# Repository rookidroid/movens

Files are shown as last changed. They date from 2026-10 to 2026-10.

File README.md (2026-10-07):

<p align="center">
  <picture>
    <source media="(prefers-color-scheme: dark)" srcset="logo/movens-logo-dark.svg">
    Movens
  </picture>
</p>

<p align="center">
  A 3D-printed, 5-axis robotic arm with a gripper, driven by an ESP32 and controlled from your browser.
</p>

---

Movens is a heavily modified fork of the [BCN3D Moveo](https://github.com/BCN3D/BCN3D-Moveo), the open-source educational arm. The mechanical design keeps Moveo's printed structure but replaces several parts. The electronics and firmware are new. Instead of Marlin on an Arduino Mega + RAMPS with G-code over USB, Movens runs its own firmware on an ESP32 and serves a web control panel over WiFi. There's nothing to install on the computer or phone you control it from.

*Movens* is Latin for "moving", from the same verb as *Moveo* ("I move").

## Features

- **Browser control panel** served by the arm itself, with light and dark themes and no internet access needed
- **Joint control:** jog or type a target angle for each of the five joints, plus the gripper servo
- **Cartesian control:** jog the tool in X / Y / Z and pitch, or go straight to a pose. Inverse kinematics picks the closest valid solution within the joint limits.
- **Synchronized moves:** all joints start and finish together, so the tool moves smoothly
- **Guided calibration** per joint: steps per degree, home angle, speed, acceleration, and soft limits. It's saved on the board and survives reboots.
- **WiFi setup from the browser:** join your network (reachable at `http://movens.local`), or fall back to the arm's own access point
- **Emergency stop** in every page, also bound to the <kbd>Esc</kbd> key
- **Over-the-air firmware updates** from the Arduino IDE once the arm is on your network
- **REST API**, so you can drive the arm from scripts as well as the web UI

## Hardware

| | |
|---|---|
| Controller | ESP32 development board (classic ESP32, e.g. *ESP32 Dev Module*) |
| Joints J1–J5 | Stepper motors, each on a STEP/DIR driver |
| Gripper | Hobby servo, driven at 700–2300 µs |
| Structure | 3D-printed parts. See [Repository layout](#repository-layout). |

### Wiring

Default pins, set in [`movens_config.h`](firmware/movens/movens_config.h):

| Joint | Role | STEP | DIR |
|---|---|---|---|
| J1 | Base yaw | 12 | 13 |
| J2 | Shoulder | 27 | 14 |
| J3 | Elbow | 25 | 26 |
| J4 | Wrist roll | 32 | 33 |
| J5 | Wrist pitch | 2 | 15 |
| Gripper | Servo signal | 4 | |

Stepper drivers need their own motor supply. Tie the drivers' logic ground to the ESP32 ground.

## Firmware

The firmware lives in [`firmware/movens`](firmware/movens) and builds with the Arduino IDE or `arduino-cli`.

### Requirements

- [Arduino-ESP32 core](https://github.com/espressif/arduino-esp32) (Boards Manager: *esp32 by Espressif Systems*)
- Libraries, from the Library Manager:
  - [FastAccelStepper](https://github.com/gin66/FastAccelStepper)
  - [ESP32Servo](https://github.com/madhephaestus/ESP32Servo)
  - [ESPAsyncWebServer](https://github.com/ESP32Async/ESPAsyncWebServer) and [AsyncTCP](https://github.com/ESP32Async/AsyncTCP)

`WiFi`, `Preferences` and `ArduinoOTA` come with the ESP32 core.

### Configure and flash

1. Open `firmware/movens/movens.ino`.
2. Review [`movens_config.h`](firmware/movens/movens_config.h): pins, stepper speed and acceleration, gripper servo range, and the access-point name and password. **Change the default AP password (`movens_1234`).**
3. Measure your arm and update the `KIN_*` link lengths in the same file. They're used by the Cartesian control.
4. Select your ESP32 board and port, then upload.

Once the arm is on your WiFi network, later updates can go over the air. Pick the `movens` network port in the Arduino IDE.

### Module layout

| File | Purpose |
|---|---|
| `movens.ino` | Setup and the main loop (Core 1) |
| `movens_config.h` | Pins, servo range, WiFi defaults, arm geometry |
| `joints.*` | Stepper engine, J1–J5 steppers, gripper servo |
| `calibration.*` | Steps ↔ degrees, soft limits, saving to flash (NVS) |
| `kinematics.*` | Forward and inverse kinematics (tool pose ↔ joint angles) |
| `commands.*` | FreeRTOS queue from web handlers (Core 0) to the motion loop (Core 1) |
| `connectivity.*` | WiFi station / access-point fallback, saved network, OTA |
| `web_server.*` | HTTP routes and REST API |
| `web_*.h` | Embedded HTML, CSS, JS and favicon for the web UI |
| `json_util.*` | Minimal JSON number parsing |

## Getting started

1. **Power on in the alignment pose.** Each joint's step counter starts at 0 at power-on, so put every joint on its alignment marks before switching on.
2. **Connect.** On first boot the arm starts an access point named `movens`. Join it and open `http://192.168.4.1`.
3. **Join your network (optional).** On the **Network** page, pick your WiFi and save. The arm restarts and joins it. Open `http://movens.local` or the IP your router assigned. If it can't connect, it falls back to the `movens` access point.
4. **Calibrate each joint** on the **Calibrate** page:
   1. Zero the counter at the alignment pose.
   2. Jog to two poses whose angles you can measure, as far apart as the joint allows, and record each one. Approach both from the same direction so backlash doesn't skew the result.
   3. Check the computed steps per degree, set speed, acceleration and soft limits, then save.
   4. Verify by commanding a few angles.
5. **Move the arm** from the **Control** page, by joint or in Cartesian space. Cartesian control needs all five joints calibrated.

Joint angle conventions, like where zero is and which way is positive, must match those described in [`movens_config.h`](firmware/movens/movens_config.h) for the kinematics to be correct.

## REST API

Every page in the web UI uses this API, and you can call it directly. POST bodies are JSON.

| Method | Path | Body / reply |
|---|---|---|
| GET | `/status` | Steps (`jN`), angles (`aN`), moving flags (`mN`) and tool pose (`x y z pitch yaw`) |
| POST | `/move` | `{joint, steps}`: relative move |
| POST | `/moveto` | `{joint, pos}`: absolute move in steps |
| POST | `/moveangle` | `{joint, deg}`: absolute move in degrees |
| POST | `/movejoints` | `{a1..a5 \| j1..j5, speed?}`: synchronized multi-joint move |
| POST | `/movepose` | `{x, y, z, pitch, yaw?, rel?, dry?, speed?}`: IK move to a tool pose |
| POST | `/setpos` | `{joint, deg}` or `{joint, steps}`: redefine current position, no motion |
| POST | `/servo` | `{us}`: gripper servo pulse width |
| POST | `/stop` | Stop all motors immediately |
| POST | `/home` | Move all joints to step 0 |
| GET / POST | `/config` | Speed and acceleration per joint |
| GET / POST | `/calib` | Calibration and saved motion profile per joint |
| GET / POST | `/wifi` | Current connection and saved network. POST `{ssid, password?}` |
| GET | `/wifiscan` | Nearby networks |

Example: move the tool 20 mm up from where it is now.

```bash
curl -X POST http://movens.local/movepose -d '{"z":20,"pitch":0,"rel":1}'
```

## Repository layout

| Path | Contents |
|---|---|
| [`firmware/movens`](firmware/movens) | Movens ESP32 firmware and web UI |
| [`cad`](cad) | Movens parts: new and modified designs (STEP / STL / 3MF) and the Fusion 360 assembly |
| [`logo`](logo) | Movens logo, icon and favicon (SVG, light and dark) |
| [`archive/moveo`](archive/moveo) | Original BCN3D Moveo files: SolidWorks CAD, Marlin firmware, BOM and user manual (not used by Movens) |
| [`archive/legacy`](archive/legacy) | Earlier Movens iterations, kept for reference |

The original [Moveo manual](archive/moveo/manual) is still the best guide to printing and assembling the shared structural parts.

## Credits

- [**BCN3D Moveo**](https://github.com/BCN3D/BCN3D-Moveo) by BCN3D Technologies, developed with the Departament d'Ensenyament of the Generalitat de Catalunya. Movens is a fork of this project.
- The Moveo is itself based on the [BetaBots Robot Arm](https://hackaday.io/project/3800-3d-printable-robot-arm) by [Andreas Hölldorfer](http://chaozlabs.blogspot.de/) ([GitHub](https://github.com/4ndreas/BetaBots-Robot-Arm-Project)).

## License

[MIT](LICENSE). The original BCN3D Moveo copyright notice is kept, as the license requires.

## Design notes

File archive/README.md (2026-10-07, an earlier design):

# Archive

Files kept for reference. Nothing here is used by the current Movens build.

## [`moveo`](moveo)

Original files from the [BCN3D Moveo](https://github.com/BCN3D/BCN3D-Moveo), which Movens is forked from.

| Path | Contents |
|---|---|
| [`cad`](moveo/cad) | SolidWorks parts and assemblies |
| [`firmware/Marlin_BCN3D_Moveo`](moveo/firmware/Marlin_BCN3D_Moveo) | Marlin firmware for Arduino Mega + RAMPS |
| [`bom`](moveo/bom) | Bill of materials |
| [`manual`](moveo/manual) | User and assembly manual |

The manual is still the best guide to printing and assembling the structural parts Movens shares with the Moveo.

## [`legacy`](legacy)

Earlier Movens iterations, superseded by the files in [`cad`](../cad). Not maintained.

| Path | Contents |
|---|---|
| [`movens.f3d`](legacy) | Older Fusion 360 assembly (current one is [`cad/movens.f3d`](../cad/movens.f3d)) |
| [`parts.f3d`](legacy), [`1M3A.STEP`](legacy) | Loose parts from earlier work |
| [`uno box`](legacy/uno%20box) | Controller enclosure from an earlier Arduino Uno build |
| [`temp`](legacy/temp) | Scratch STLs |

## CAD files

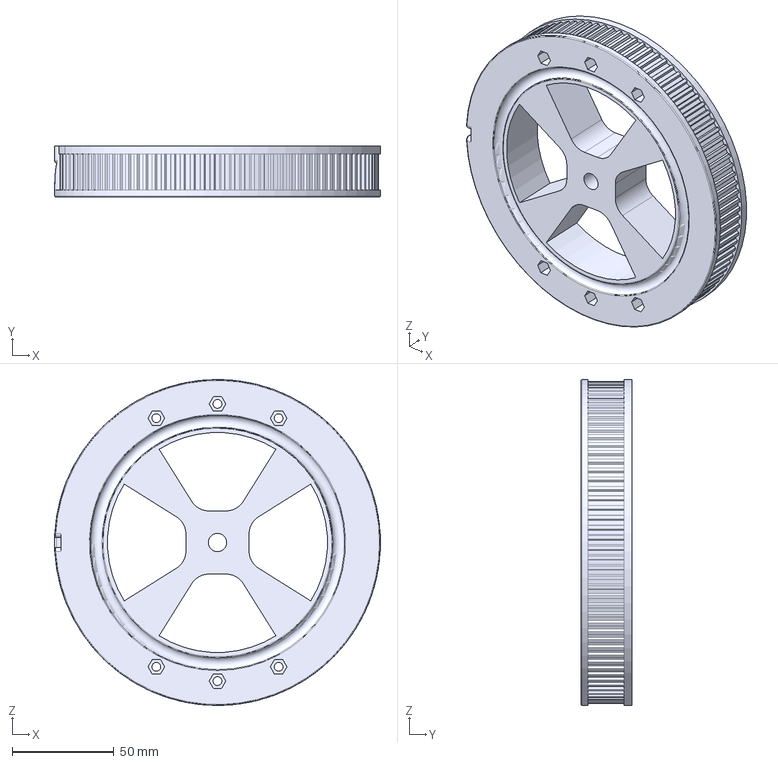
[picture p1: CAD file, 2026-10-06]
cad/movens base wheel.step
160.0 x 25.0 x 160.0 mm

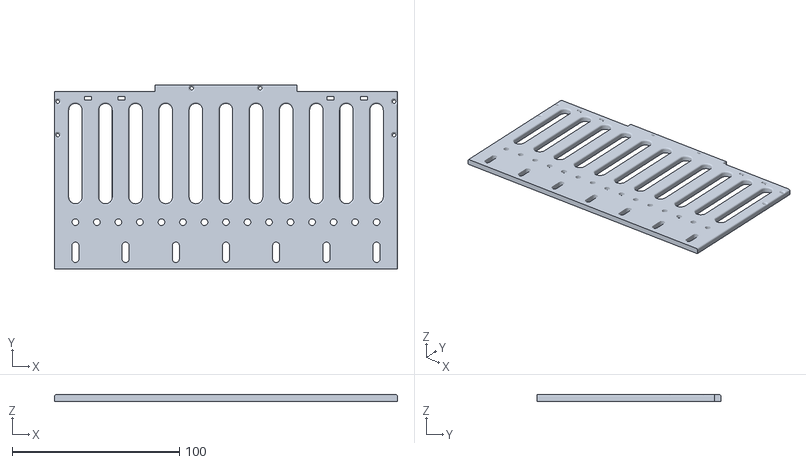
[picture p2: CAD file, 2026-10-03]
temp/side_long.stl
205.0 x 110.0 x 4.00

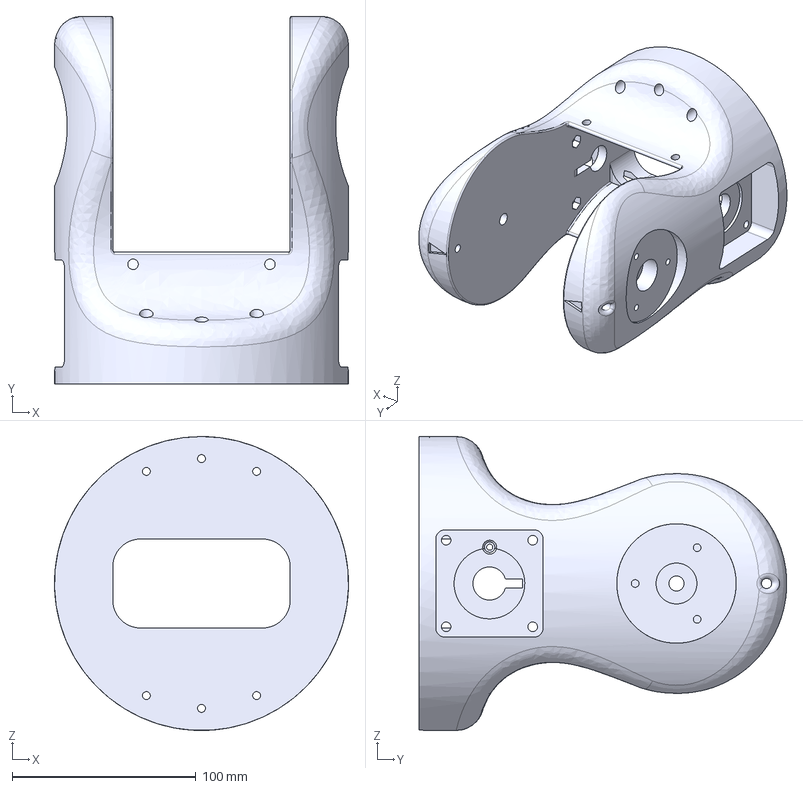
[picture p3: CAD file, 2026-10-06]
cad/movens j2.step
160.0 x 200.0 x 160.0 mm

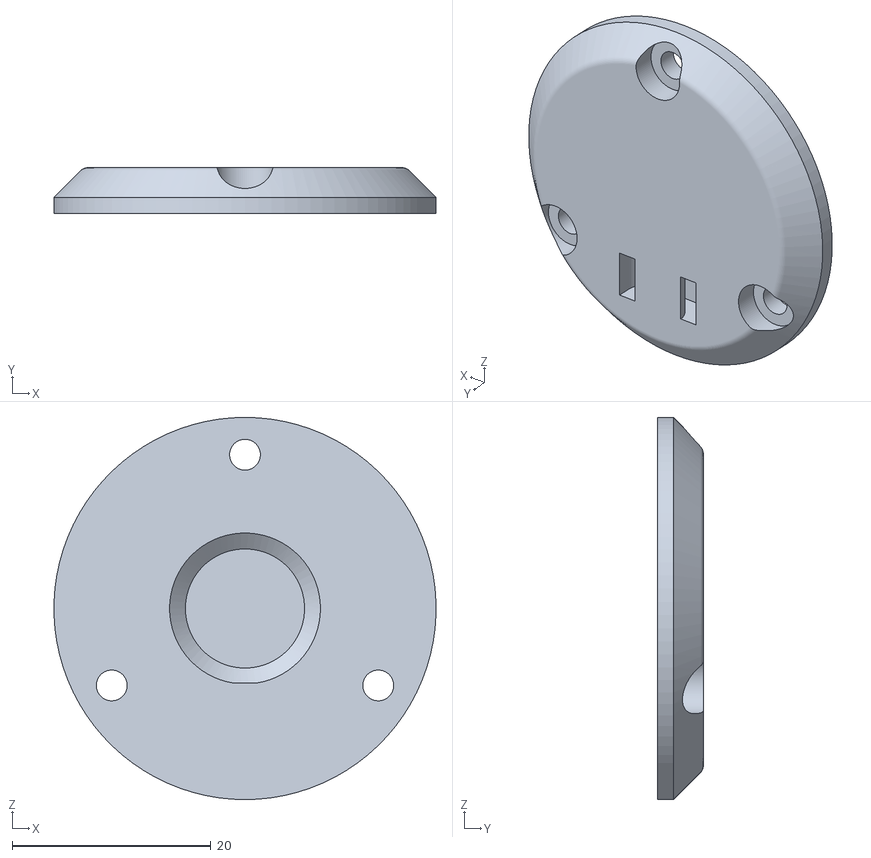
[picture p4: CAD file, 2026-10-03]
temp/Tapa 4M1_fixed.stl
38.5 x 4.60 x 38.5

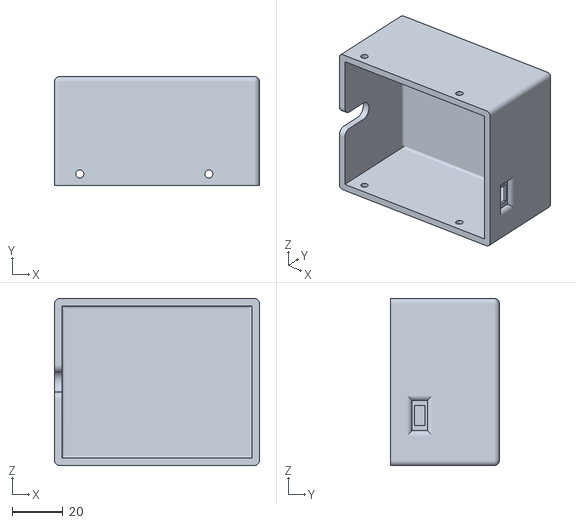
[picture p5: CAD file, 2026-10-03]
temp/ESP32 top.stl
81.0 x 43.0 x 66.0

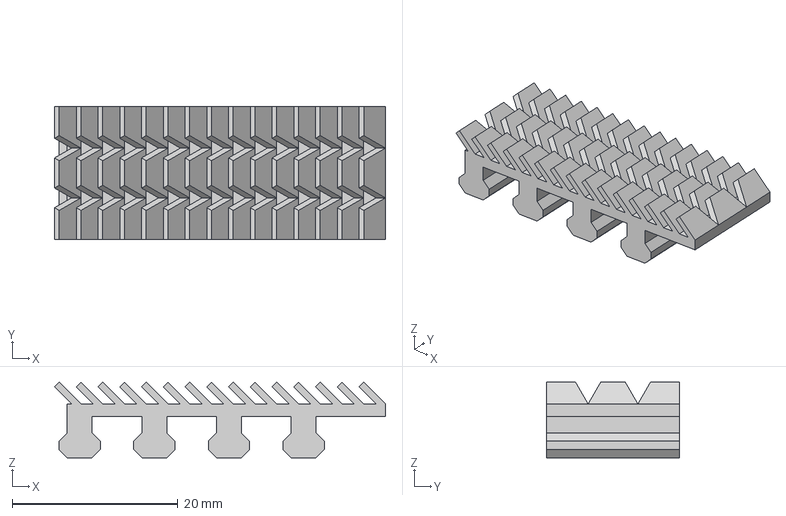
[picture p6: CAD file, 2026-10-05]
cad/Gripper.step
39.9 x 16.0 x 9.12 mm

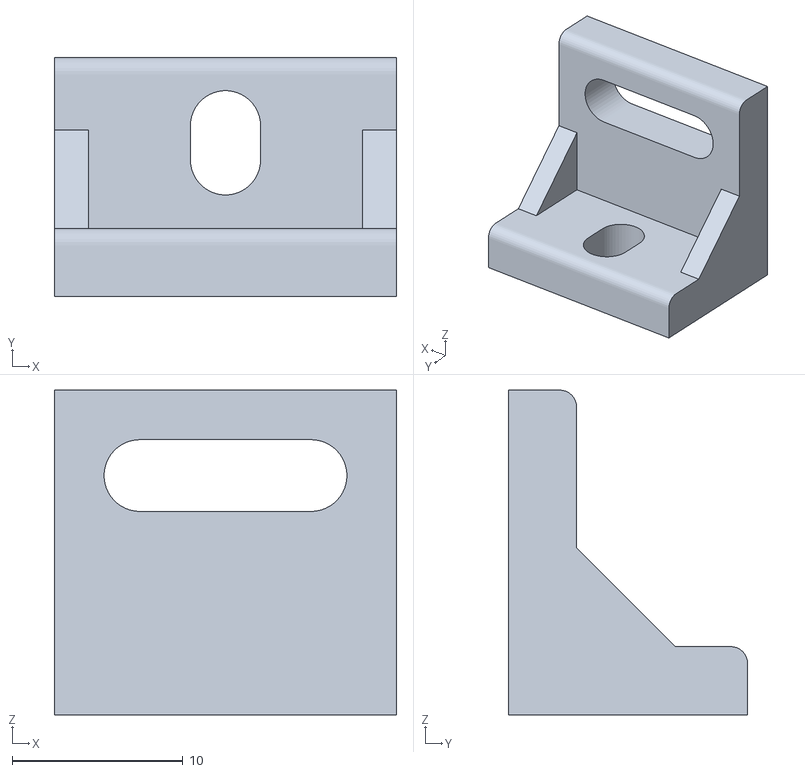
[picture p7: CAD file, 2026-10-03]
temp/Body37.stl
20.0 x 14.0 x 19.0

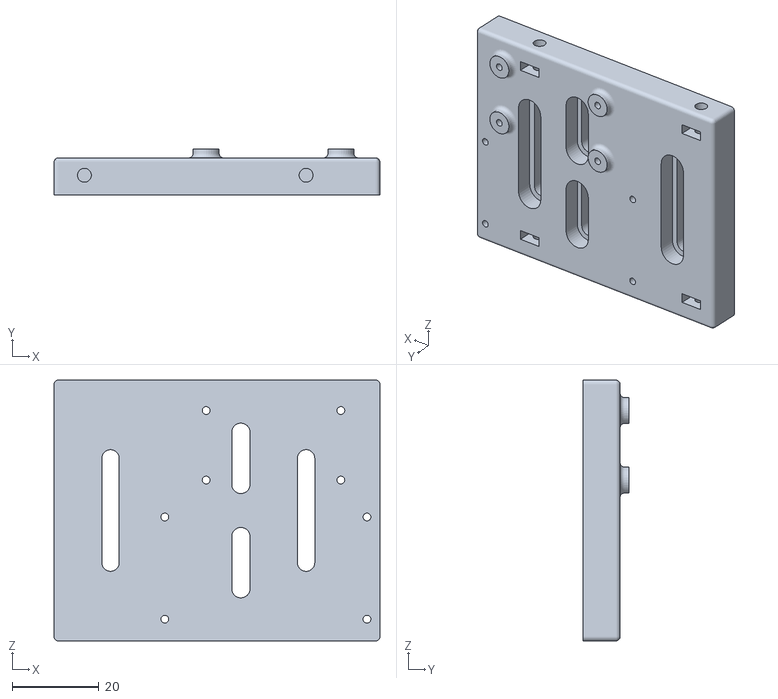
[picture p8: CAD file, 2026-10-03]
temp/ESP32 base.stl
75.0 x 10.5 x 60.0

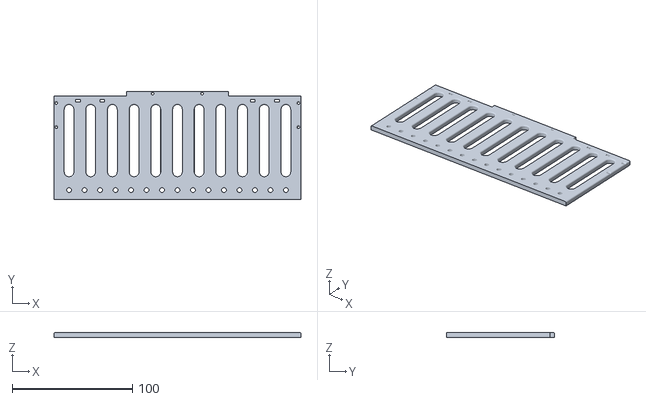
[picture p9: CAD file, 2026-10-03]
temp/side.stl
205.0 x 90.0 x 4.00

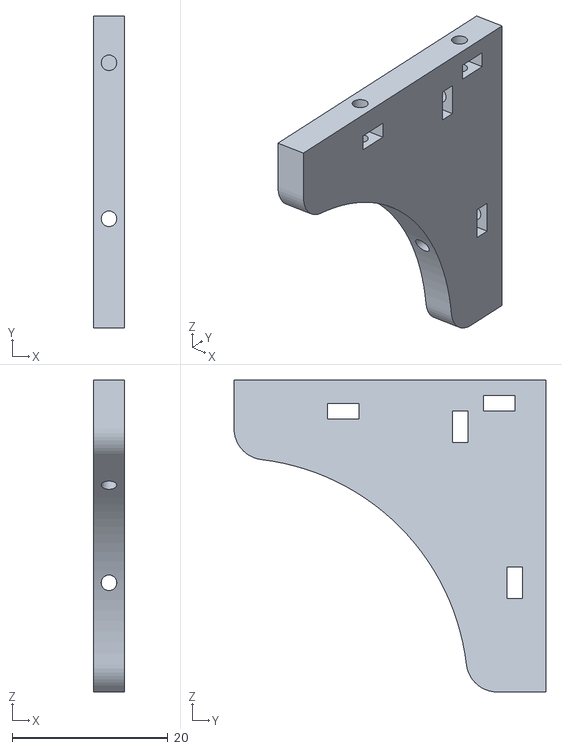
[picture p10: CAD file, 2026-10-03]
temp/Body36.stl
4.00 x 40.0 x 40.0

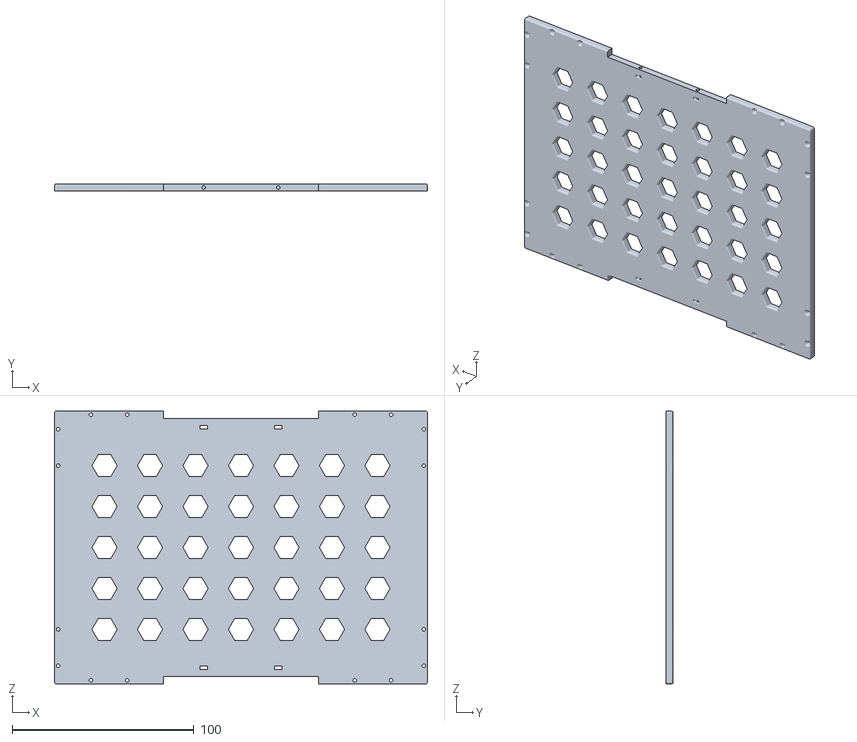
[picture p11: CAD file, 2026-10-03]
temp/top.stl
205.0 x 4.00 x 150.0

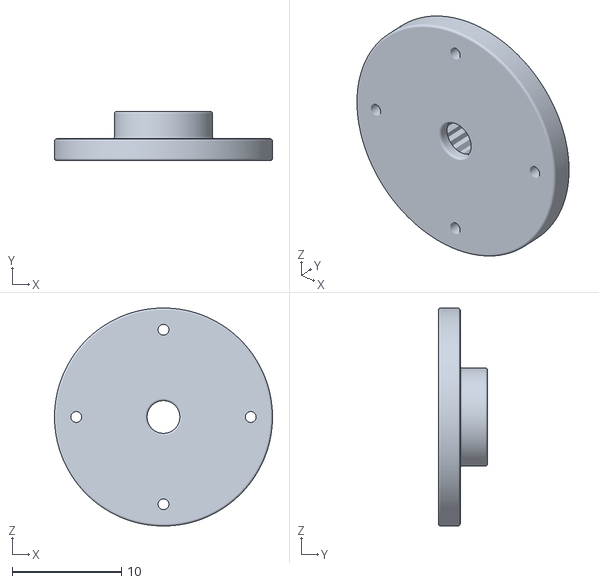
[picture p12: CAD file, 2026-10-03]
temp/servo_horn_small.stl
20.0 x 4.50 x 20.0

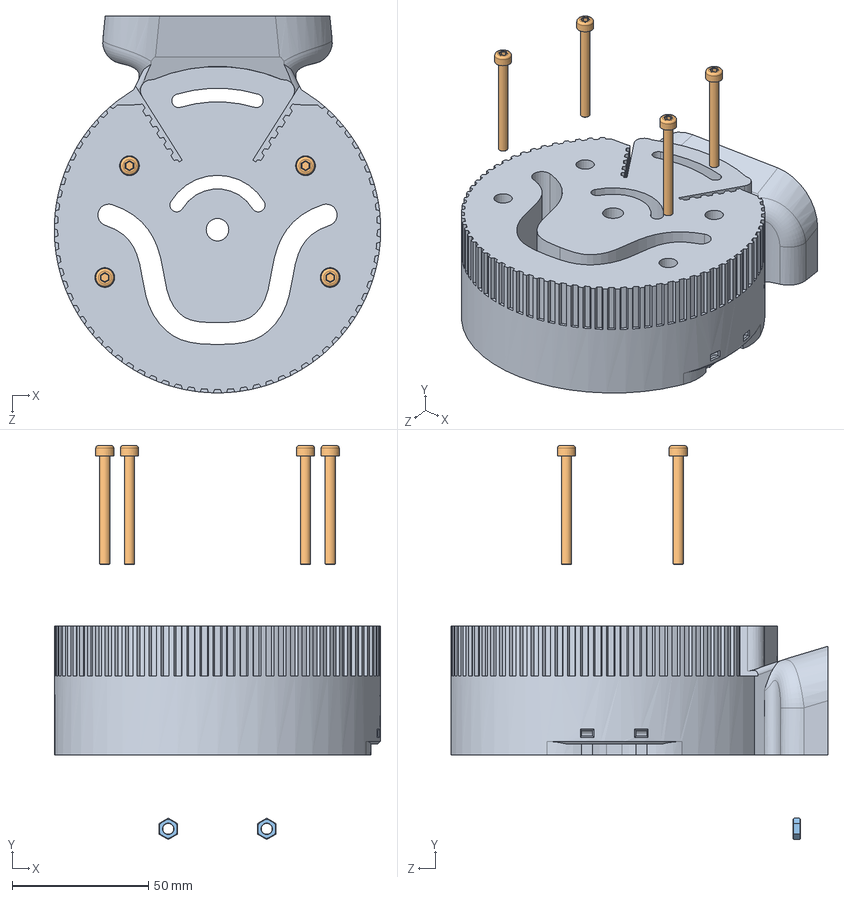
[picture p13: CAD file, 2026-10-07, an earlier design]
archive/moveo/cad/2M2M assembly.SLDASM
120.0 x 144.8 x 138.5 mm
2M2MA
M4x40 x 4
M4 Nut x 2

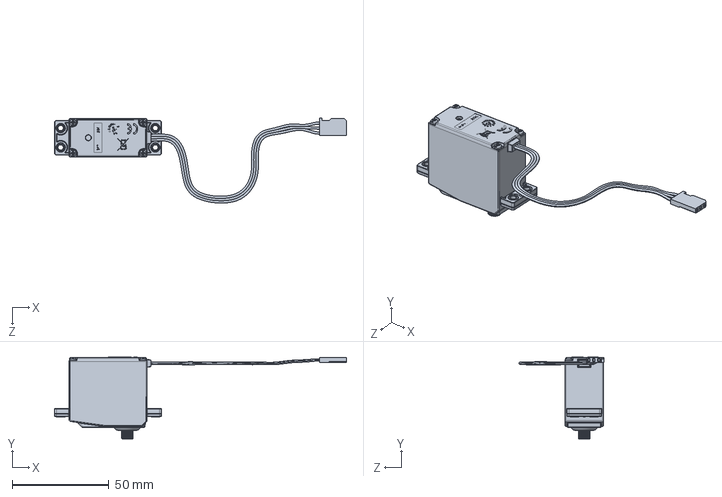
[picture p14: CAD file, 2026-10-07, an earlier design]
archive/moveo/cad/2.SLDASM
151.2 x 42.3 x 44.1 mm

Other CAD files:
cad/movens base.step
archive/legacy/uno box/Assem1.SLDASM
archive/moveo/cad/2M2.SLDASM
archive/moveo/cad/Module Fan Assembly.SLDASM
CAD files/movens.f3d
archive/legacy/1M3A.STEP
archive/legacy/movens.f3d
archive/legacy/parts.f3d
archive/legacy/uno box/Case_5_14.STL
archive/legacy/uno box/Case_6_14.STL
archive/legacy/uno box/Part1.SLDPRT
archive/legacy/uno box/Part2.SLDPRT
archive/legacy/uno box/Top5_14.STL
archive/legacy/uno box/Top6-14.STL
archive/moveo/cad/1M1B.SLDPRT
archive/moveo/cad/1M2A.SLDPRT
archive/moveo/cad/1M3.SLDASM
archive/moveo/cad/1M3A.SLDPRT
archive/moveo/cad/2M1 assembly.SLDASM
archive/moveo/cad/2M1D.SLDPRT
archive/moveo/cad/2M2 assembly.SLDASM
archive/moveo/cad/2M2HA.SLDPRT
archive/moveo/cad/2M2MA.SLDPRT
archive/moveo/cad/3M1.SLDASM
archive/moveo/cad/3M1D.SLDPRT
archive/moveo/cad/3M2.SLDASM
archive/moveo/cad/3M2C.SLDPRT
archive/moveo/cad/3M2CC.SLDPRT
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

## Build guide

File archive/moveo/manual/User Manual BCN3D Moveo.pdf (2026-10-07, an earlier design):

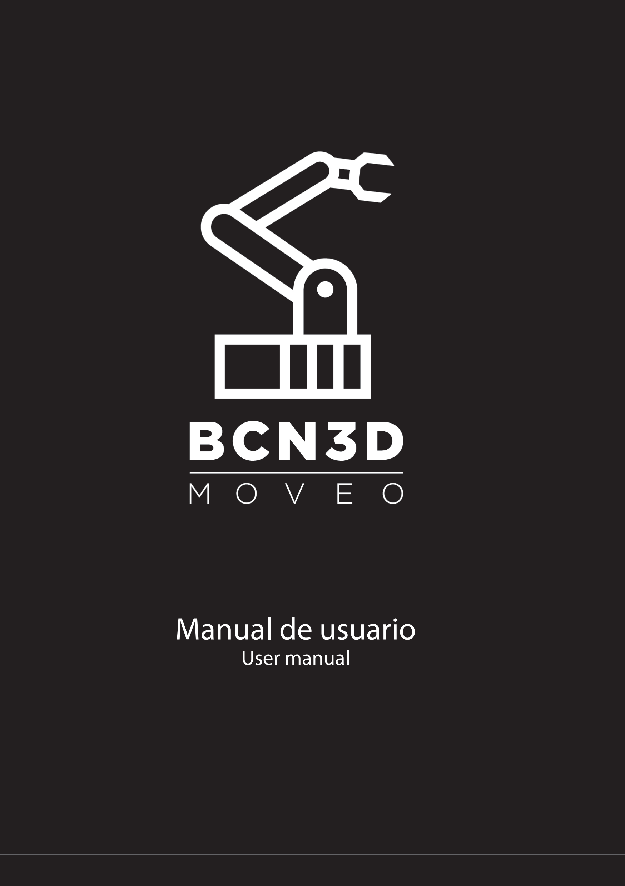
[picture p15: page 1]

# Manual de usuario

# User manual

2 - Manual de usuario User manual

Manual de montaje
Assembly manual

Manual de usuario User manual

¿Cómo usar el BCN3D Moveo? How to use the BCN3D Moveo?

Instalación del firmware
Firmware installation

Sobre el BCN3D Moveo
About de BCN3D Moveo

## ÍNDICE INDEX

3 - 4

6 - 39

40 - 42

43 - 45

Manual de usuario User manual - 3

## Sobre el BCN3D Moveo About the BCN3D Moveo

BCN3D Technologies sigue dando pasos importantes para cumplir con su objetivo de acercar las tecnologías de fabricación digital y aditiva al público general. En esta ocasión queremos presentar el BCN3D Moveo, un brazo robótico diseñado desde cero y desarrollado por nuestros ingenieros en colaboración con el Departament d’Ensenyament de la Generalitat de Catalunya, cuya estructura está impresa en 3D y su tecnología controlada por el software Arduino.
Moveo, totalmente funcional a día de hoy, ha nacido, como todos los demás productos salidos de BCN3D Technologies, con voluntad formativa y abierta.

EL PORQUÉ DE BCN 3D MOVEO

Una de las preocupaciones del Departament d’Ensenyament es el elevado coste de los materiales que deben usar los alumnos de formación de grado para realizar sus prácticas. En este sentido, un brazo robótico Open Source, modificable por los alumnos y reproducible a bajo coste podía copar varios de los itinerarios formativos existentes: Diseño mecánico, automatismos, programación industrial, etc.
Así pues, el BCN3D Moveo debería permitir a los institutos disfrutar de un equipamiento personalizable, modificable y de fácil acceso para el alumno a un precio lejos de los equipamientos industriales que normalmente habían tenido que adquirir, pero con unas prestaciones suficientes para los fines formativos.
Como área de la Fundació CIM, BCN3D Technologies comparte la vocación formativa de su alma máter. Es por dicho motivo que cuando el Departament d’Ensenyament se puso en contacto con nosotros para proponernos el proyecto un año atrás, no dudamos en aceptar la propuesta.
Una vez tuvimos el brazo diseñado y fabricado, se inició la última parte del proyecto que consistía en un workshop de montaje y puesta en marcha para 15 institutos de Cataluña, realizado en las instalaciones de BCN3D Technologies.
Estos institutos ya cuentan con el BCN3D Moveo en sus aulas y talleres, y deberán presentar prácticas que acrediten su conocimiento del equipo durante el mes de setiembre.

BCN3D Technologies keeps taking important steps in order to achieve his goal of bringing the digital manufacturing technology to everyone. In this occasion we are presenting the BCN3D Moveo, a robotic arm design from scratch and developed by our engineers in collaboration with the Departament d’Ensenyament from the Generalitat de Catalunya. Its structure is fully printed using additive manufacturing technologies and its electronics are controlled by the software Arduino.
Moveo, fully functional nowadays, has been born, as all the BCN3D Technologies products, with an open and educational wish.

WHY BCN 3D MOVEO

One of the Departament d’Ensenyament worries is the high price of the materials the grade students must use on their internships. Holding that in mind, an Open Source robotic arm, adaptable by the students and low cost reproducible could take several educational itineraries: mechanical design, automatism, industrial programing, etc.
Thus, the BCN3D Moveo should allow the educational centers to enjoy a modifiable and easily accessible for the students, at a price far lower than the usual industrial equipment they used to have to acquire, with enough output for training purposes. As a Fundació CIM area, BCN3D Technologies shares its educational vocation. That is the reason why when the Departament d’Ensenyament contacted us in order to suggest and offer this project a year ago we didn’t hesitate on taking that opportunity. Once we had the robotic arm designed and manufactured we started the last phase of the project, which consisted on an assembling and fine tuning workshop for 15 institutes around Catalonia, which took place in the BCN3D Technologies.
These institutes already have the BCN3D Moveo in their classrooms and workshops, and will have to present an internship program that proves their knowledge about the arm during September.

## Sobre el BCN3D Moveo About the BCN3D Moveo

TECNOLOGÍA OPEN SOURCE: LA PLATAFORMA
GITHUB

Como hiciéramos con todos nuestros productos, los archivos del BCN3D Moveo estarán a la disposición de todo aquel que quiera acceder a ellos. Gracias a la plataforma Github, un espacio en el que los usuarios comparten sus diseños de forma libre, cualquier persona podrá obtener toda la información necesaria para montarse su propio BCN3D Moveo en casa.
A diferencia de los otros productos de BCN3D Technologies, el BCN3D Moveo no será comercializado. El proyecto se ha realizado con el ánimo de dar una aportación más a la comunidad a partir de la idea del Departament d’Ensenyament.
BCN3D liberará el conocimiento del Moveo en sus repositorios en Github como se ha venido haciendo con los productos oficiales de BCN3D Techologies. De esta manera, se espera que la comunidad y los centros formativos que estén interesados puedan fabricar sus propios robots.
Así, entre los archivos que subiremos a dicha plataforma incluimos el “bill of materials” (BOM), en el que se detallan todos los componentes necesarios para montar el brazo, así como los diseños CAD, para que todo el mundo pueda modificar el diseño del BCN3D Moveo a su gusto. De la misma forma, los usuarios de Github podrán encontrar los archivos STL para la impresión de la estructura del brazo, y el manual de montaje del mismo que estará en español e inglés.
Gracias a este proyecto impulsado por el Departament d’Ensenyament y desarrollado por BCN3D Technologies, todo el mundo podrá fabricarse un brazo robótico en casa, sin necesidad de tener un amplio conocimiento técnico. Así, os animamos a todos a fabricaros el BCN3D Moveo y compartir los resultados en las redes con el hashtag #BCN3DMoveo.

OPEN SOURCE TECHNOLOGY: GITHUB

As we have done with all our developed pordutcs, the BCN3D Moveo files will be available for everyone. Thanks to the platform Github, a website where users around the world share their designs, anyone will be able to obtain all the necessary information in order to assemble his own BCN3D Moveo at home.
Unlike the other BCN3D products, the Moveo won’t be commercialized. The project has been born and developed in order to make a move for the community progress starting from the Departament d’Ensenyament idea.
Nevertheless, BCN3D will fee all the Moveo know how on our Github account, as we have been doing with all the BCN3D Technologies products. Thus, the users will be able to find the bill of material (BOM), where all the needed components for the assembling of the arm come detailed, as the CAD designs, so anyone will be able to modify the BCN3D Moveo design as they wish.
Furthermore, the Github users will find the STL files for the structure printing and the assembling, fine tuning and firmware upload manuals, which will be available both in English and Spanish.
Thanks to this project motivated by the Departament d’Ensenyament and developed by BCN3D Technologies everyone will be able to fabricate their own robotic arm at home, no highly technical knowledge needed. Therefore, we encourage you to fabricate the BCN3D Moveo and share the results on the social networks using the hashtag #BCN3DMoveo.

# Manual de montaje

# Assembly manual

## Montaje del módulo 1 Module 1

x8

BOM | Descripción Description | Cant Qty
115 | Tornillo M5 x 20mm Screw M5 x 20mm | 8
16 | Rodamiento 5mm x 16mm x 5mm Bearing 5mm x 16mm x 5mm | 8
30 | Espaciador 5mm x 10mm Spacer 5mm x 10mm | 8

121 | Tuerca autoblocante M5 M5 locknut | 8
15 | Rodamiento 8mm x 22mm x 7mm Bearing 8mm x 22mm x 7mm | 2
- | 1M2A Base rotatoria 1M2A Rotary plate | 1

## Montaje del módulo 1 Module 1 assembly

x1

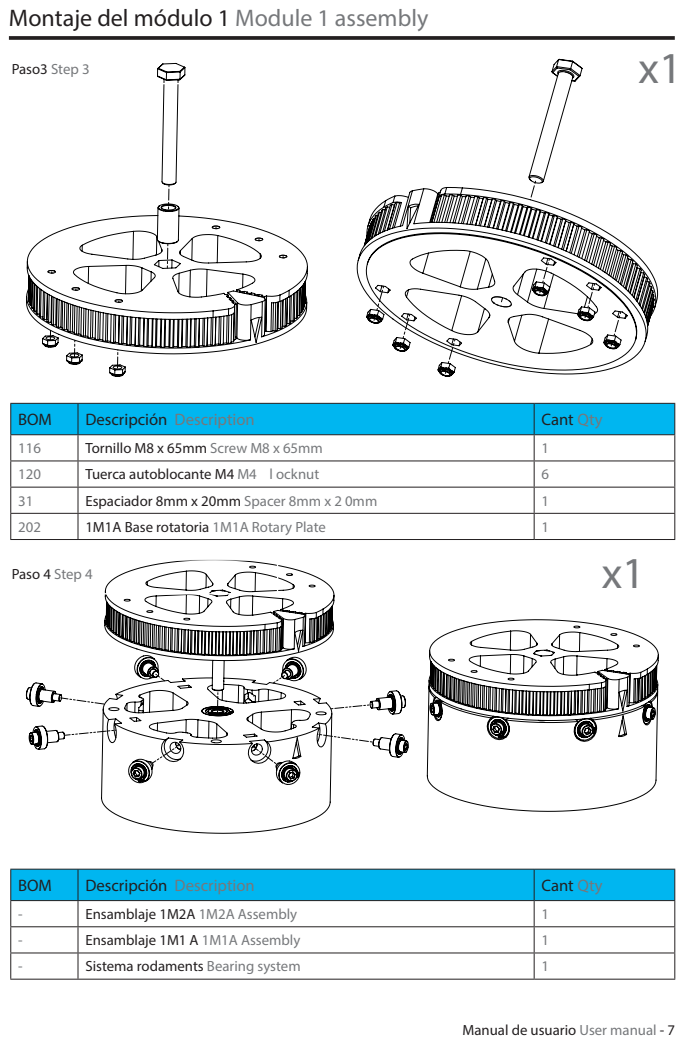
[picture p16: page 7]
Paso3 Step 3; Paso 4 Step 4

BOM | Descripción Description | Cant Qty
116 | Tornillo M8 x 65mm Screw M8 x 65mm | 1
120 | Tuerca autoblocante M4 M4 l ocknut | 6
31 | Espaciador 8mm x 20mm Spacer 8mm x 2 0mm | 1
202 | 1M1A Base rotatoria 1M1A Rotary Plate | 1

- | Ensamblaje 1M2A 1M2A Assembly | 1
- | Ensamblaje 1M1 A 1M1A Assembly | 1
- | Sistema rodaments Bearing system | 1

## Montaje del módulo 1 Module 1 assembly

BOM ID | Descripción Description | Cant Qty
204 | Pieza impresa 1M3 Printed part 1M3 | 1
1 | Motor nema 17 largo Large nema 17 motor | 1
101 | Tornillo M3 x 10mm M3 x 8mm screw | 4
22 | Polea 5mm 5mm pulley | 1

## Montaje del módulo 2 Module 2 assembly

x1

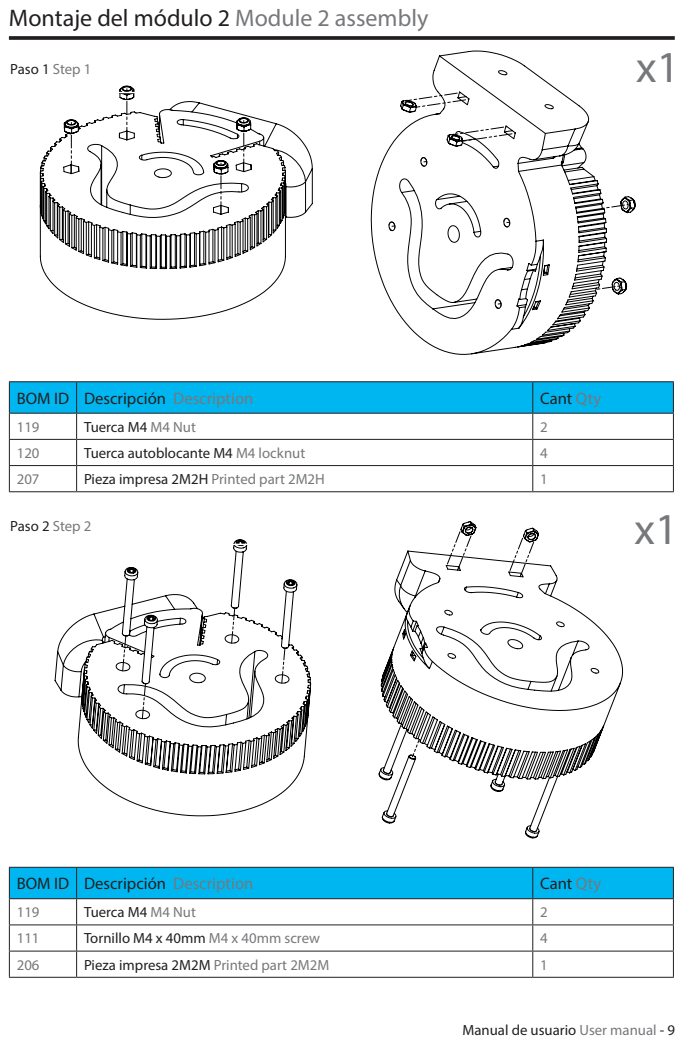
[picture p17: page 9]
Paso 1 Step 1; Paso 2 Step 2

BOM ID | Descripción Description | Cant Qty
119 | Tuerca M4 M4 Nut | 2
120 | Tuerca autoblocante M4 M4 locknut | 4
207 | Pieza impresa 2M2H Printed part 2M2H | 1

111 | Tornillo M4 x 40mm M4 x 40mm screw | 4
206 | Pieza impresa 2M2M Printed part 2M2M | 1

## Montaje del módulo 2 Module 2 assembly

BOM ID | Descripción Description | Cant Qty
- | Ensamblaje 2M2H 2M2H assembly | 2
- | Ensamblaje 2M2M 2M2M assembly | 2

## Montaje del módulo 2 Module 2 assembly

x1

BOM ID | Descripción Description | Cant Qty
208 | Pieza impresa T2M1D Printed part T2M1D | 1
117 | Tornillo M4 x 20mm M4 x 20mm screw | 1
119 | Tuerca M4 M4 nut | 1
118 | Tuerca M3 M3 nut | 1
17 | Rodamiento 4mm x 13mm x 5mm Bearing 4mm x 13mm x 5mm | 3

209 | Pieza impresa T2M1I Printed part T2M 1I | 1

## Montaje del módulo 2 Module 2 assembly

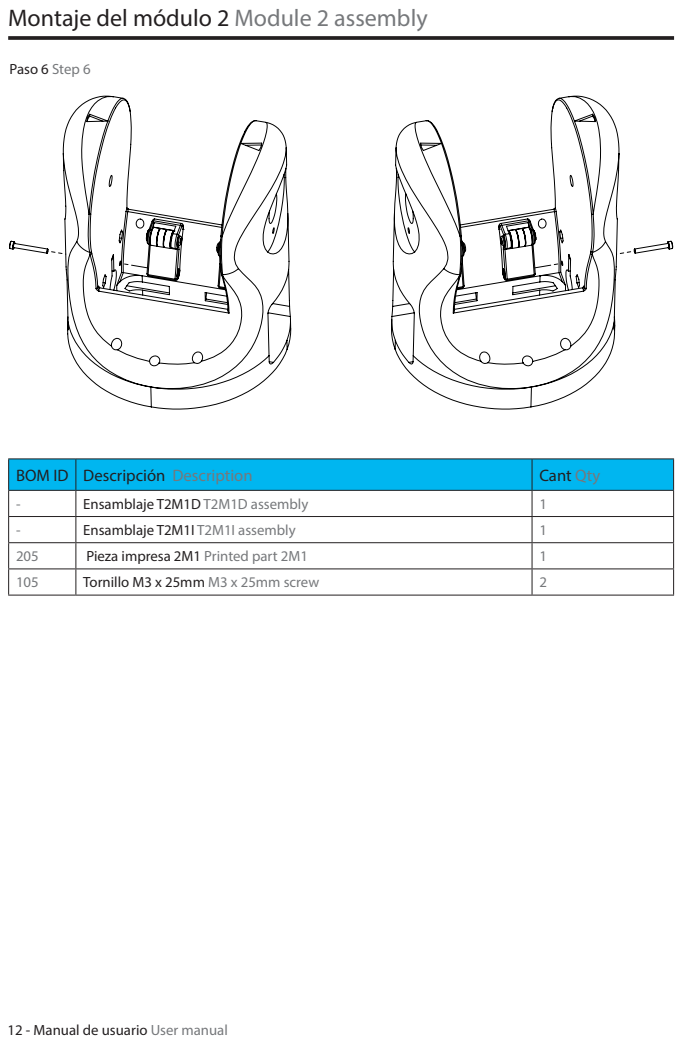
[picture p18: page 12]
Paso 6 Step 6

BOM ID | Descripción Description | Cant Qty
- | Ensamblaje T2M1D T2M1D assembly | 1
- | Ensamblaje T2M1I T2M1I assembly | 1
205 | Pieza impresa 2M1 Printed part 2M1 | 1
105 | Tornillo M3 x 25mm M3 x 25mm screw | 2

## Montaje del módulo 2 Module 2 assembly

BOM ID | Descripción Description | Cant Qty
9 | Motor Nema 23 Nema 23 motor | 2
114 | Tornillo M5 x 14mm M5 x 14mm screw | 8
121 | Tuerca autoblocante M5 M5 locknut | 8

## Montaje del módulo 2 Module 2 assembly

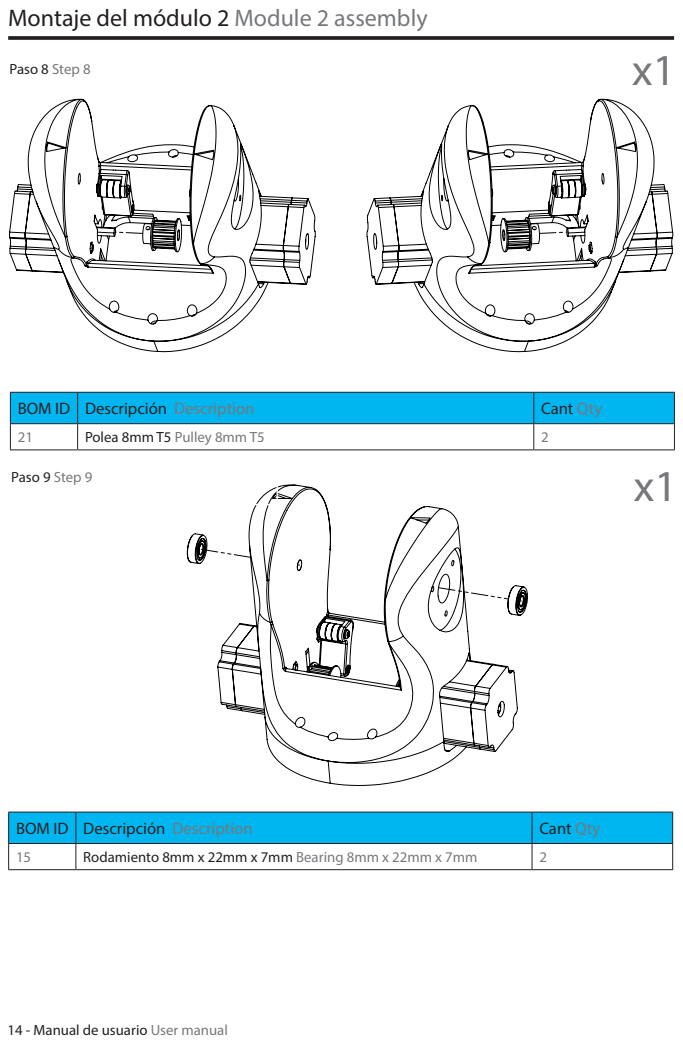
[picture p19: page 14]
Paso 8 Step 8; Paso 9 Step 9

BOM ID | Descripción Description | Cant Qty
21 | Polea 8mm T5 Pulley 8mm T5 | 2

15 | Rodamiento 8mm x 22mm x 7mm Bearing 8mm x 22mm x 7mm | 2

## Montaje del módulo 2 Module 2 assembly

BOM ID | Descripción Description | Cant Qty
- | Ensamblaje 2M2 2M2 assembly | 1

12 | Barra lisa 134mm Smooth bar 134mm | 1

## Montaje del módulo 2 Module 2 assembly

BOM ID | Descripción Description | Cant Qty
19 | Inserto M4 M4 insert | 2

20 | Inserto M3 M3 insert | 2
101 | Tornillo M3 x 10mm M3 x 10mm screw | 6
229 | Pieza impresa Tapa 2M1 Printed part Tapa 2M1 | 1

## Montaje de la herramienta Tool assembly

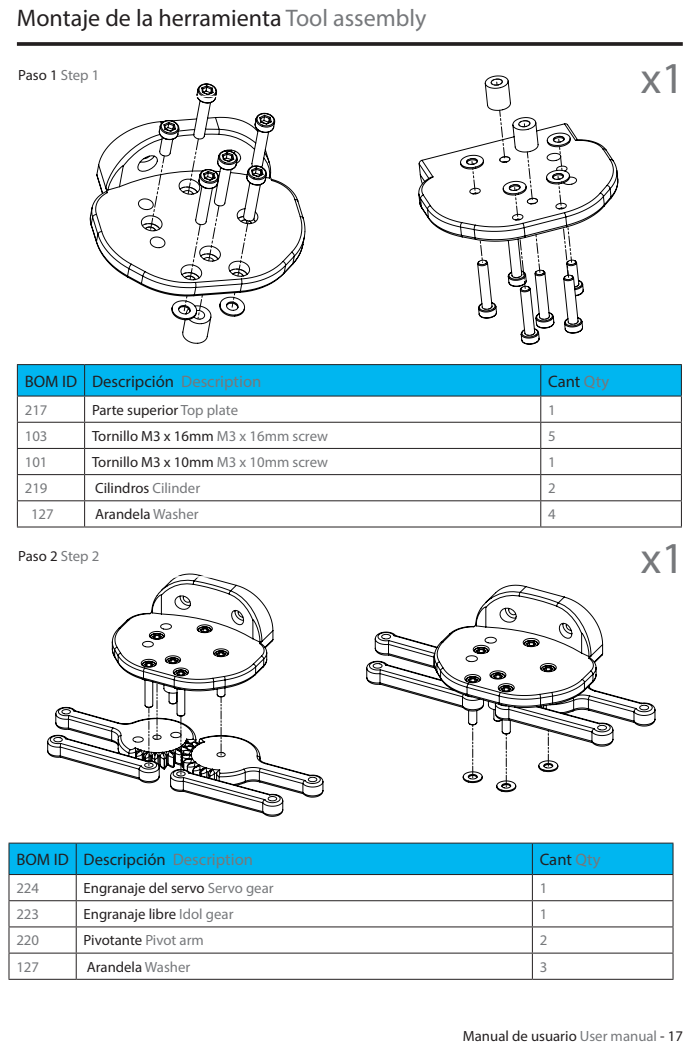
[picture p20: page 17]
Paso 1 Step 1; Paso 2 Step 2

BOM ID | Descripción Description | Cant Qty
217 | Parte superior Top plate | 1
103 | Tornillo M3 x 16mm M3 x 16mm screw | 5
101 | Tornillo M3 x 10mm M3 x 10mm screw | 1
219 | Cilindros Cilinder | 2
127 | Arandela Washer | 4

224 | Engranaje del servo Servo gear | 1
223 | Engranaje libre Idol gear | 1
220 | Pivotante Pivot arm | 2
127 | Arandela Washer | 3

## Montaje de la herramienta Tool assembly

BOM ID | Descripción Description | Cant Qty
218 | Parte inferior Bottom plate | 1
118 | Tuerca M3 M3 nut | 4

221 | Pinza izquiera Left gripper | 1
222 | Pinza derecha Right gripper | 1
103 | Tornillo M3 x 16mm M3 x 16mm screw | 8

## Montaje del módulo 3 Module 3 assembly

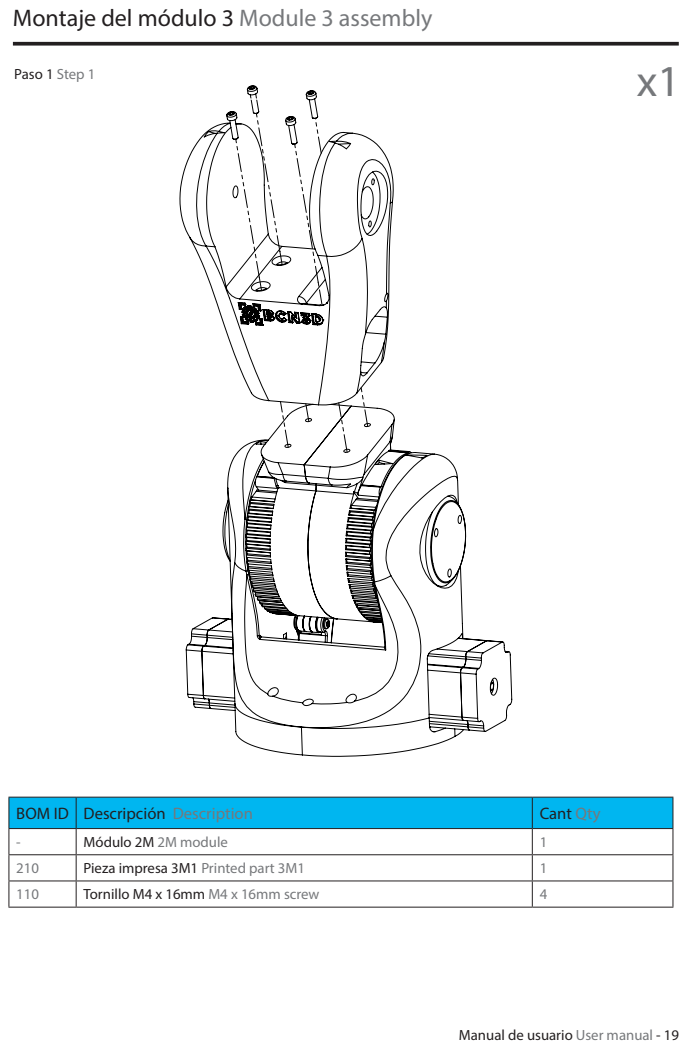
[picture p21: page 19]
Paso 1 Step 1

BOM ID | Descripción Description | Cant Qty
- | Módulo 2M 2M module | 1
210 | Pieza impresa 3M1 Printed part 3M1 | 1
110 | Tornillo M4 x 16mm M4 x 16mm screw | 4

## Montaje del módulo 3 Module 3 assembly

BOM ID | Descripción Description | Cant Qty
212 | Pieza impresa T3M1 Printed part T3M1 | 1
17 | Rodamiento 4mm x 13mm x 5mm Bearing 4mm x 13mm x 5mm | 3
123 | Tornillo M4 x 20mm M4 x 20mm screw | 1
119 | Tuerca M4 M4 nut | 1

- | Módulo T3M1 T3M1 module | 1
107 | Tornillo M3 x 40mm M3 x 40mm screw | 1
118 | Tuerca M3 M3 nut | 1

## Montaje del módulo 3 Module 3 assembly

BOM ID | Descripción Description | Cant Qty
210A | Pieza impresa 3M2C Printed part 3M2C | 1
11 | Motor Nema-17 34mm Nema-17 motor 34mm | 1
101 | Tornillo M3 x 10mm M3 x 10mm screw | 2

24 | Acoplador 8mm - 5mm Coupling 8mm- 5mm | 1
23 | Barra roscada 42mm Rod bar 42mm | 1
15 | Rodamiento 8mm x 22mm x 7mm Bearing 8mm x 22mm x 7mm | 1

## Montaje del módulo 4 Module 4 assembly

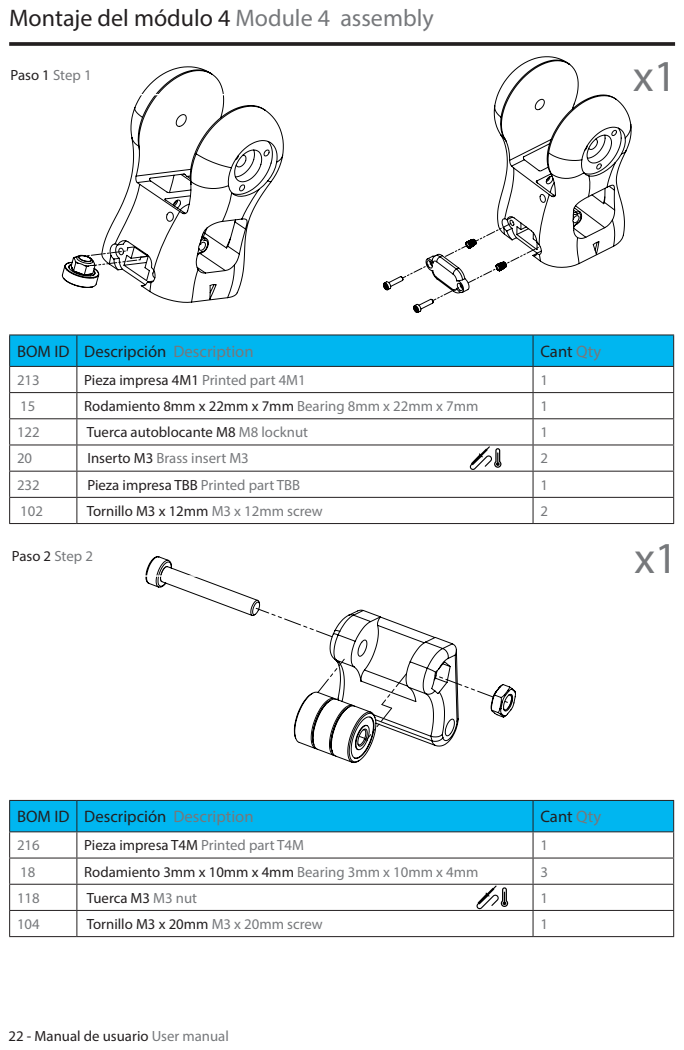
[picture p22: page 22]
Paso 1 Step 1; Paso 2 Step 2

BOM ID | Descripción Description | Cant Qty
213 | Pieza impresa 4M1 Printed part 4M1 | 1
15 | Rodamiento 8mm x 22mm x 7mm Bearing 8mm x 22mm x 7mm | 1
122 | Tuerca autoblocante M8 M8 locknut | 1
20 | Inserto M3 Brass insert M3 | 2
232 | Pieza impresa TBB Printed part TBB | 1
102 | Tornillo M3 x 12mm M3 x 12mm screw | 2

216 | Pieza impresa T4M Printed part T4M | 1
18 | Rodamiento 3mm x 10mm x 4mm Bearing 3mm x 10mm x 4mm | 3
118 | Tuerca M3 M3 nut | 1
104 | Tornillo M3 x 20mm M3 x 20mm screw | 1

## Montaje del módulo 4 Module 4 assembly

BOM ID | Descripción Description | Cant Qty
214 | Pieza impresa 4M2 Printed part 4M2 | 1
215 | Pieza impresa 4M2C Printed part 4M2C | 1
118 | Tuerca M3 M3 nut | 3
117 | Tornillo M4 x 25mm M4 x 25mm screw | 2
120 | Tuerca autoblocante M4 M4 Locknut | 4

## Montaje del módulo 4 Module 4 assembly

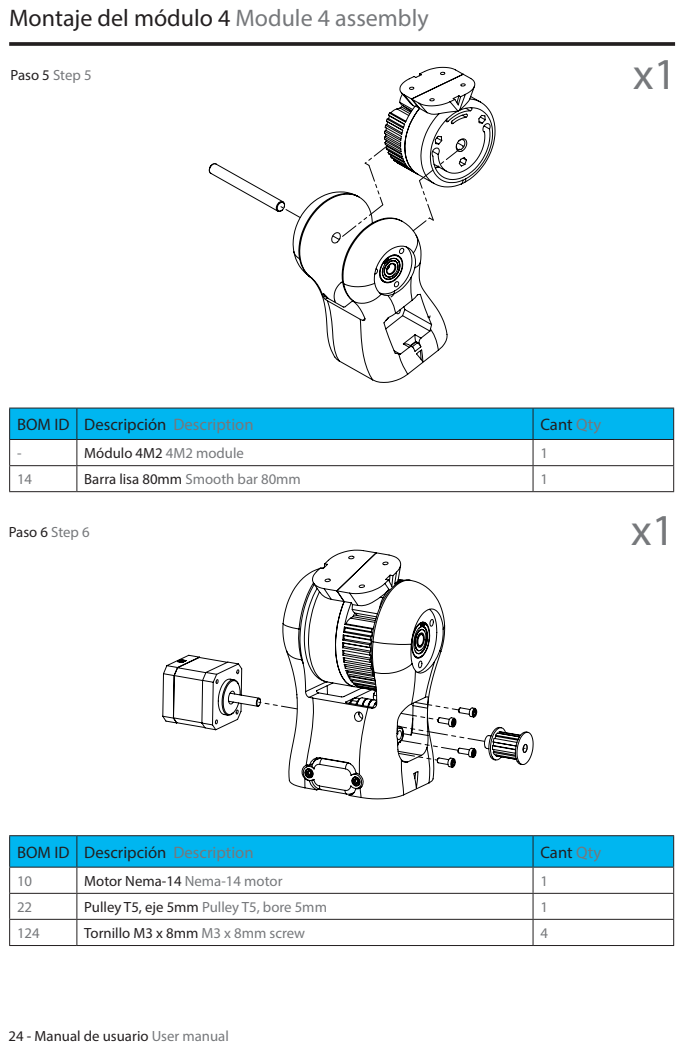
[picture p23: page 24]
Paso 5 Step 5; Paso 6 Step 6

BOM ID | Descripción Description | Cant Qty
- | Módulo 4M2 4M2 module | 1
14 | Barra lisa 80mm Smooth bar 80mm | 1

10 | Motor Nema-14 Nema-14 motor | 1
22 | Pulley T5, eje 5mm Pulley T5, bore 5mm | 1
124 | Tornillo M3 x 8mm M3 x 8mm screw | 4

## Montaje del módulo 4 Module 4 assembly

BOM ID | Descripción Description | Cant Qty
20 | Inserto M3 M3 insert | 6
231 | Pieza impresa Tapa 4M1 Printed part tapa 4M1 | 6
102 | Tornillo M3 x 12mm M3 x 12mm screw | 2

- | Módulo herramienta Tool module | 1
103 | Tornillo M3 x 16mm M3 x 16mm screw | 4

## Montaje del módulo 4 Module 4 assembly

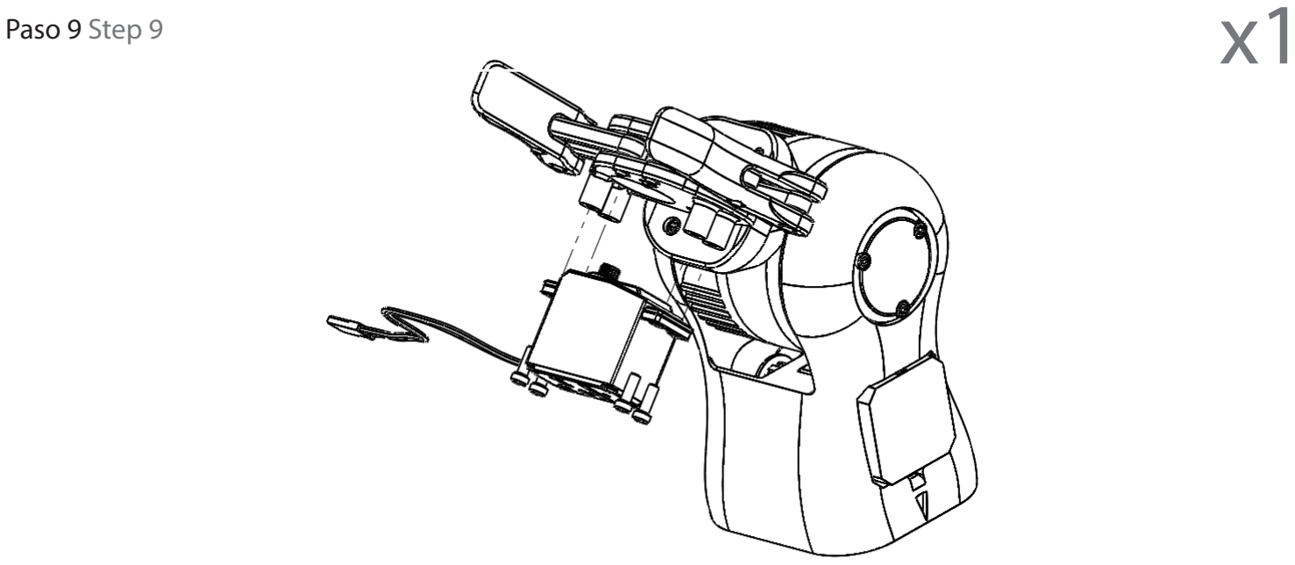
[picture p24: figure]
Paso 9 Step 9

BOM ID | Descripción Description | Cant Qty
7 | Servo motor Servo motor | 1
101 | Tornillo M3 x 10mm M3 x 10mm screw | 4

## Montaje del módulo 3 Module 3 assembly

BOM ID | Descripción Description | Cant Qty
- | Ensamblaje módulo 4 Tool module | 1
103 | Tornillo M3 x 16mm M3 x 16mm screw | 4

## Montaje del módulo 3 Module 3 assembly

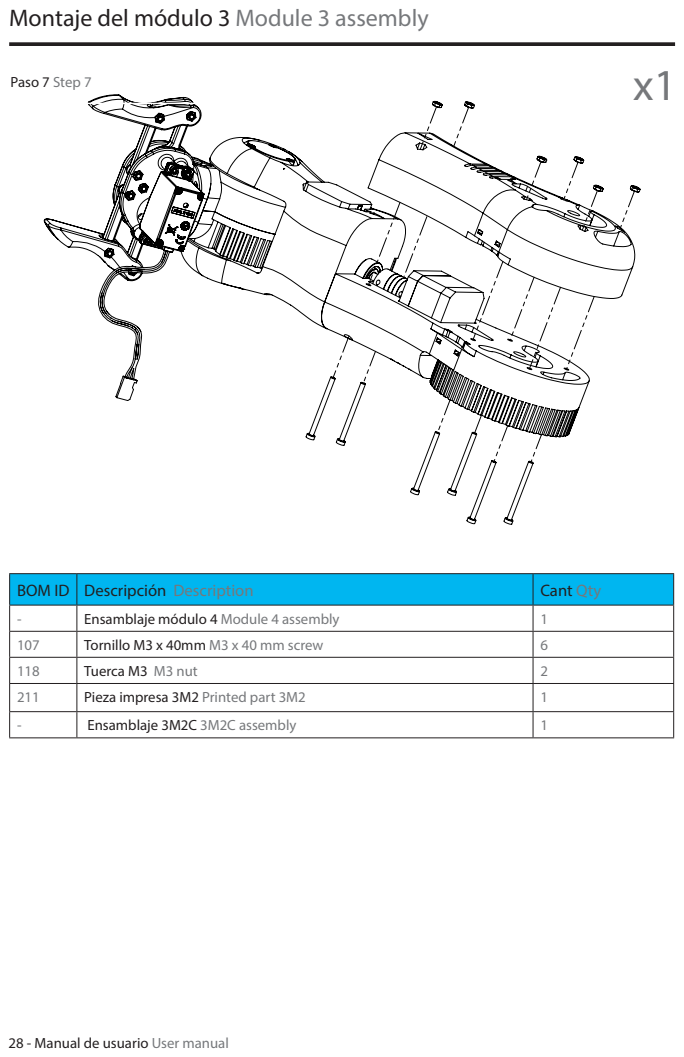
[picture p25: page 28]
Paso 7 Step 7

BOM ID | Descripción Description | Cant Qty
- | Ensamblaje módulo 4 Module 4 assembly | 1
107 | Tornillo M3 x 40mm M3 x 40 mm screw | 6
118 | Tuerca M3 M3 nut | 2
211 | Pieza impresa 3M2 Printed part 3M2 | 1
- | Ensamblaje 3M2C 3M2C assembly | 1

## Montaje del módulo 3 Module 3 assembly

BOM ID | Descripción Description | Cant Qty
15 | Rodamiento 8mm x 22mm x 7mm Bearing 8mm x 22mm x 7mm | 2

## Montaje del módulo 3 Module 3 assembly

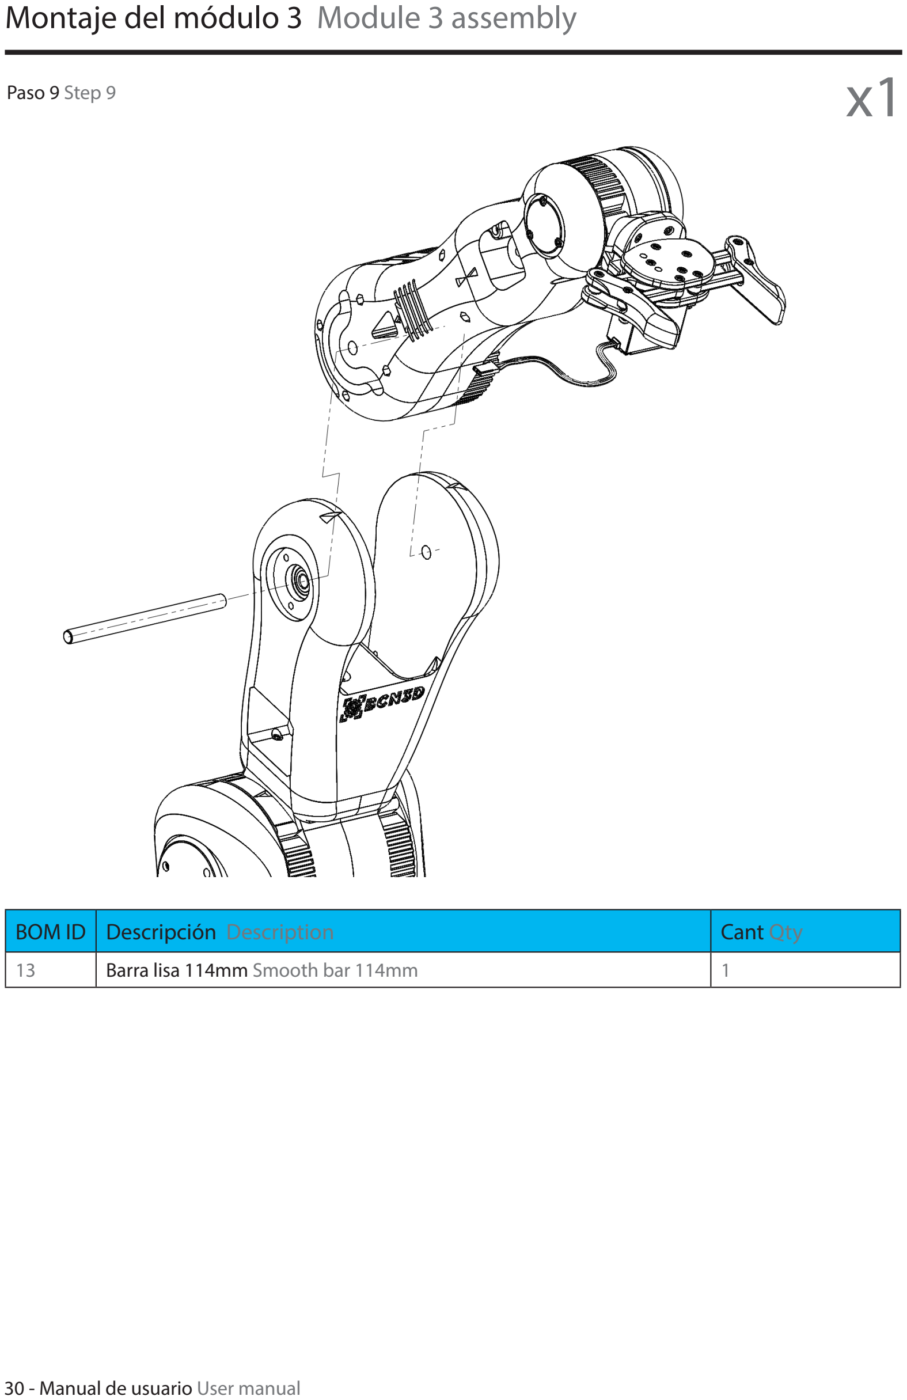
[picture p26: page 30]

BOM ID | Descripción Description | Cant Qty
13 | Barra lisa 114mm Smooth bar 114mm | 1
Paso 9 Step 9 | x1

## Montaje del módulo 3 Module 3 assembly

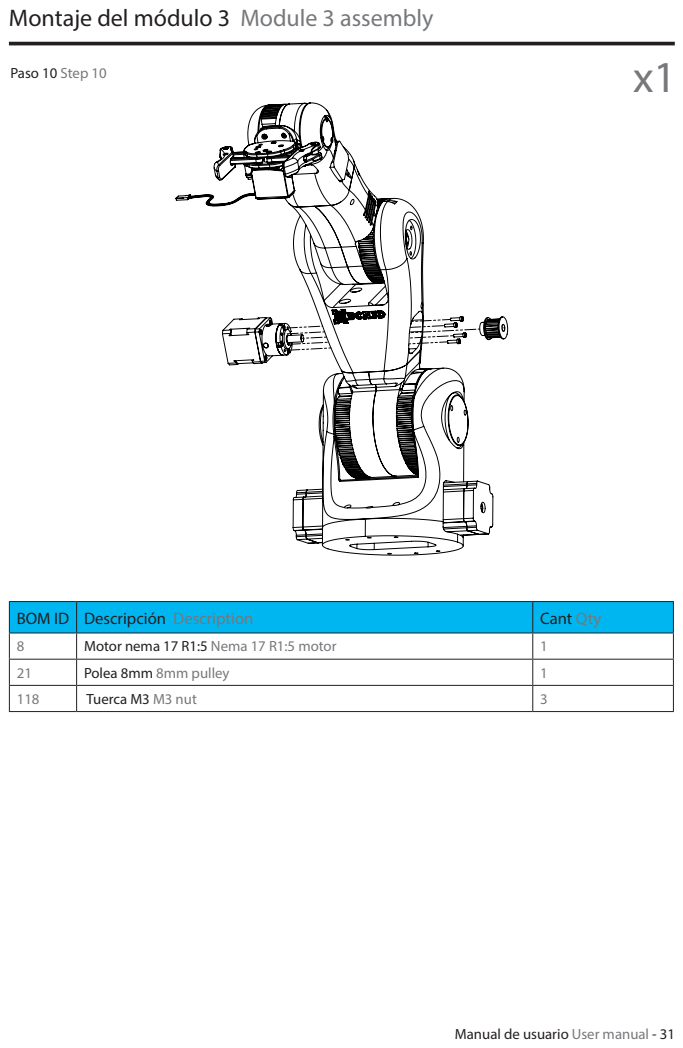
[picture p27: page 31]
Paso 10 Step 10

BOM ID | Descripción Description | Cant Qty
8 | Motor nema 17 R1:5 Nema 17 R1:5 motor | 1
21 | Polea 8mm 8mm pulley | 1
118 | Tuerca M3 M3 nut | 3

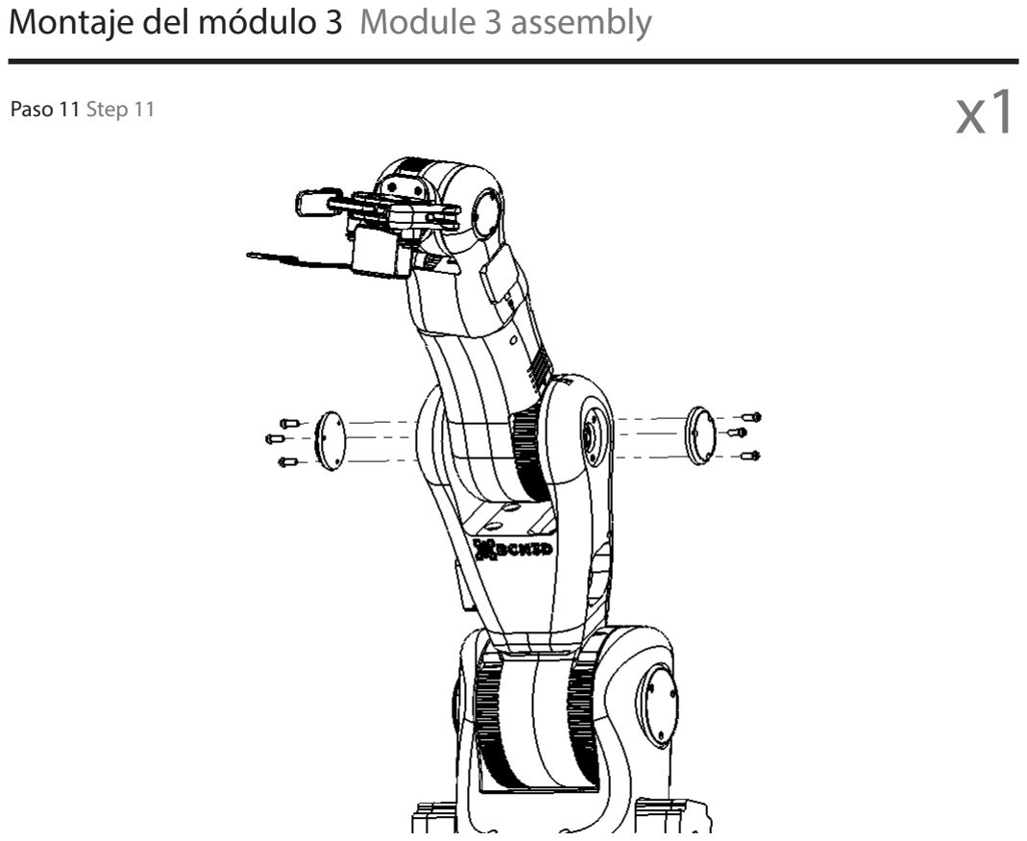
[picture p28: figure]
Montaje del módulo 3 Module 3 assembly; Paso 11 Step 11

BOM ID | Descripción Description | Cant Qty
230 | Pieza impresa tapa 3M1 Printed part tapa 3M1 | 2
101 | Tronillo M3 x 10mm M3 x 10mm srew | 1

## Montaje de la base Base assembly

BOM ID | Descripción Description | Cant Qty
- | Módulo 1M2 1M2 module | 1
32 | Base 550mm x 550mm 550mm x 550mm base | 1
111 | Tornillo M4 x 40mm M4 x 40mm screw | 4
120 | Tuerca autoblocante M4 M4 locknut | 2

## Montaje de la base Base assembly

BOM ID | Descripción Description | Cant Qty
- | Módulo 1M1 1M1 module | 1
112 | Tronillo M4 x 45mm M4 x 45mm srew | 6

## Montaje de la base Base assembly

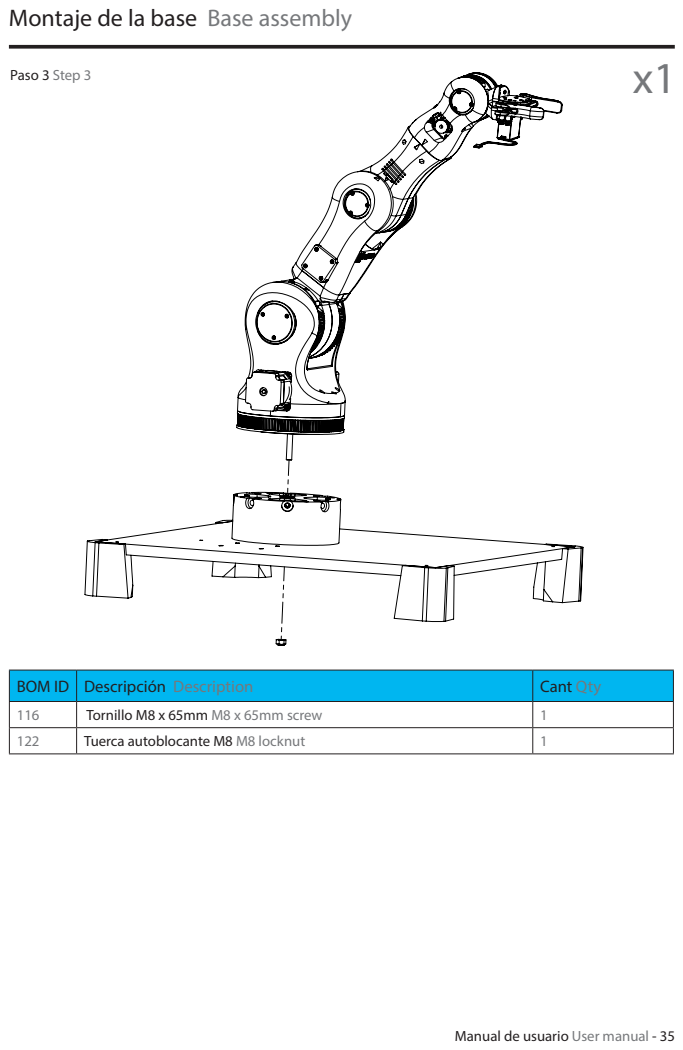
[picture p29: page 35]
Paso 3 Step 3

BOM ID | Descripción Description | Cant Qty
116 | Tornillo M8 x 65mm M8 x 65mm screw | 1
122 | Tuerca autoblocante M8 M8 locknut | 1

## Montaje de la base Base assembly

BOM ID | Descripción Description | Cant Qty
- | Módulo 1M3 1M3 module | 1
120 | Tuerca autoblocante M4 M4 locknut | 4
125 | Tornillo M4 x 30mm M4 x 30mm screw | 4

## Conexionado Connections

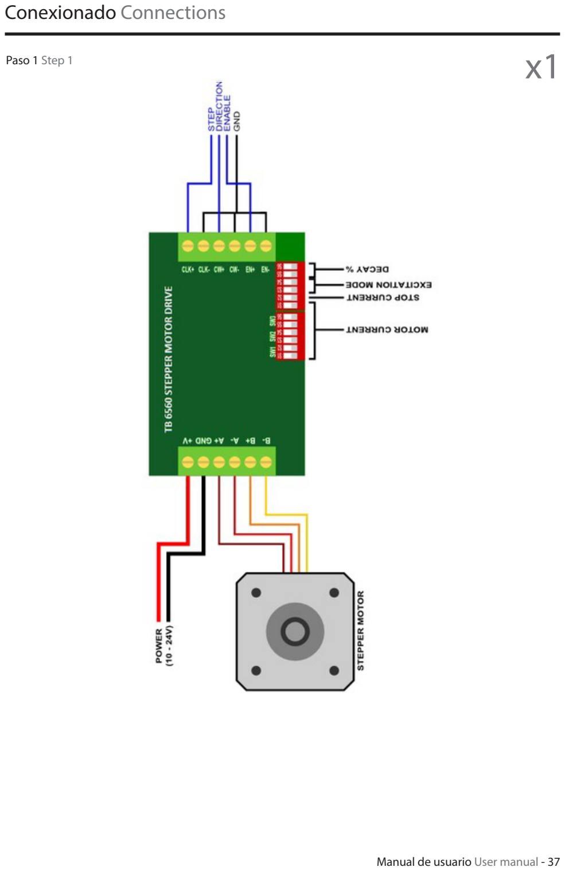
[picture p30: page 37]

Paso 1 Step 1 | x1

## Montaje de la base Base assembly

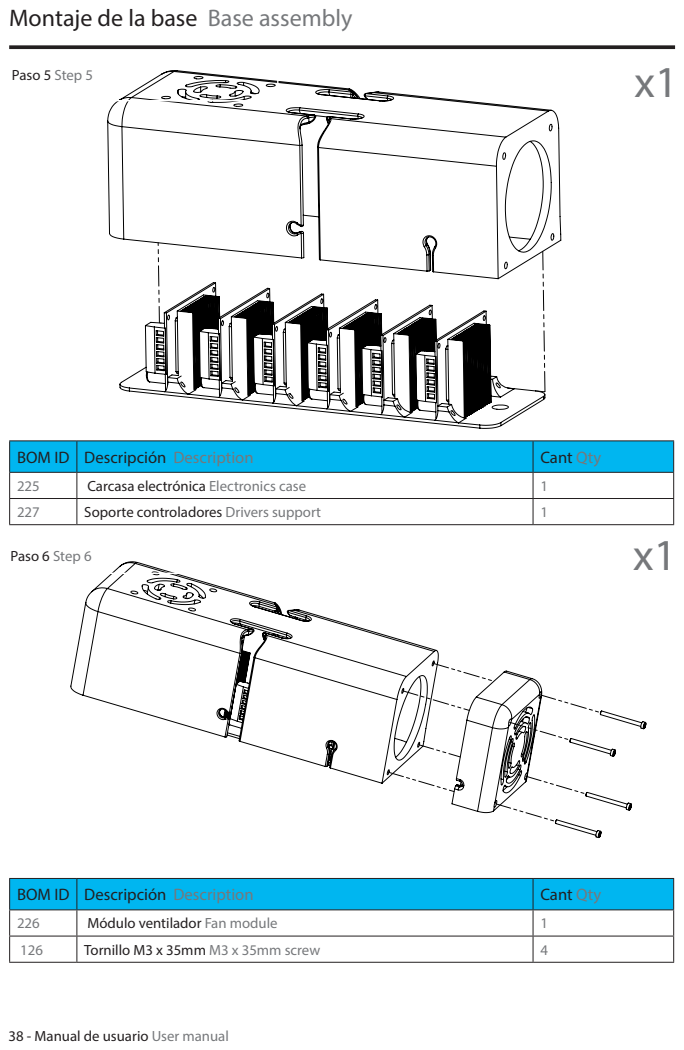
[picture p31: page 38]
Paso 5 Step 5; Paso 6 Step 6

BOM ID | Descripción Description | Cant Qty
225 | Carcasa electrónica Electronics case | 1
227 | Soporte controladores Drivers support | 1

226 | Módulo ventilador Fan module | 1
126 | Tornillo M3 x 35mm M3 x 35mm screw | 4

## Montaje de la base Base assembly

BOM ID | Descripción Description | Cant Qty
- | Módulo caja electrónica Electronics case module | 1
125 | Tornillo M4 x 30mm M4 x 30mm screw | 2

## Instalación del firmware Firmware installation

Arduino IDE

Arduino IDE es una plataforma que permite escribir código en un entorno limpio y ordenado. Una vez terminado podemos cargarlo en el arduino con solo pulsar un botón.
Estos són los passos a seguir para cargar el firmware. En nuestro caso, el firmware se llama “Marlin_BCN3D_Moveo” y está en una carpeta llamada Firmware.

Arduino IDE

Arduino IDE is a platform that allows you to write code in a clean and tidy environment. Once the code is written it, we can upload it to the arduino with just touching a button.
These are the steps to load the firmware. In our case, the firmware is called “Marlin_BCN3D_Moveo” and is located in a folder called Firmware.

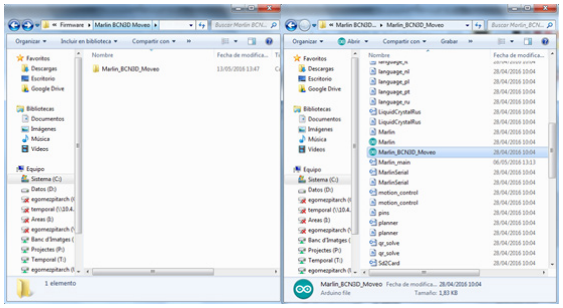
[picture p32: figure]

Una vez localizado el archivo “Marlin_BCN3D_Moveo.ino” hacer doble click en él para abrirlo. Cuando se haya cargado hacer click en herramientas y dirigirse a los apartados de “Placa”, “Procesador” y “Puerto”. Conectamos el Arduino en el PC. Abrimos el apartado de placa y seleccionamos nuestro modelo, Arduino Mega 2560.

Once you have located “Marlin_BCN3D_Moveo. ino” file, double-click on it to open it.
Click “Tools”, go to “Board”, and select Arduino Mega 2560.

## Instalación del firmware Firmware installation

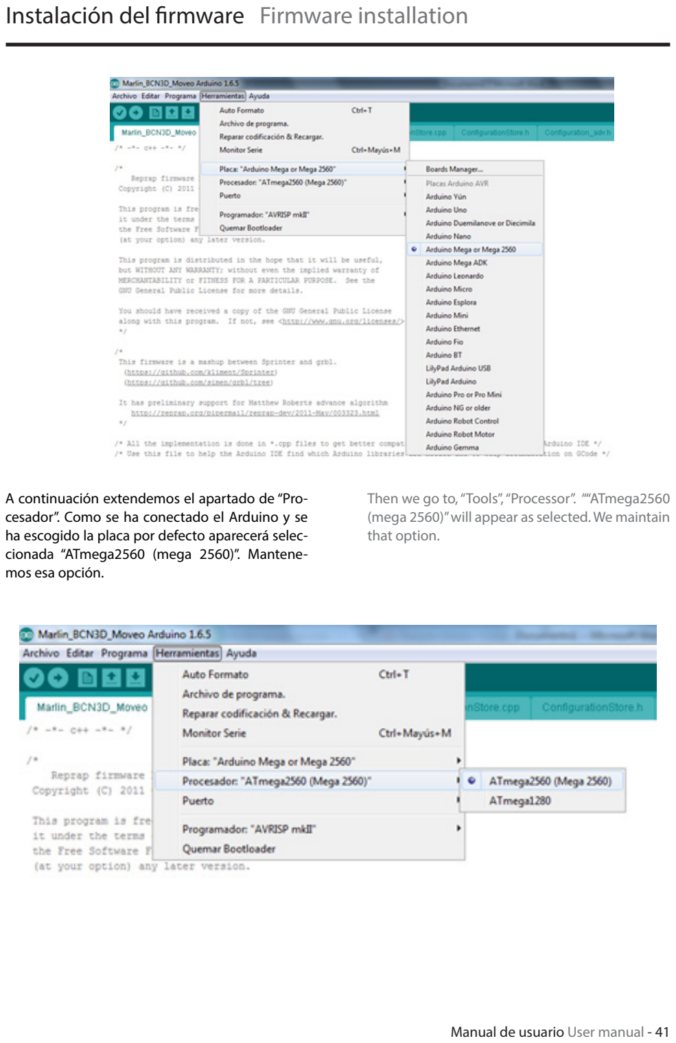
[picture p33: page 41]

A continuación extendemos el apartado de “Procesador”. Como se ha conectado el Arduino y se ha escogido la placa por defecto aparecerá seleccionada “ATmega2560 (mega 2560)”. Mantenemos esa opción.

Then we go to, “Tools”, “Processor”. ““ATmega2560 (mega 2560)” will appear as selected. We maintain that option.

## Instalación del firmware Firmware installation

El último parámetro es el del puerto. Hay que seleccionar el puerto que contenga el modelo de nuestra placa en el nombre, por ejemplo COM16 “Arduino Mega or Mega 2560”.

The last parameter is the “Tools”, “port”. You have to select the port that contains the model of your plaque in the name, eg COM16 “Arduino Mega or Mega 2560”.

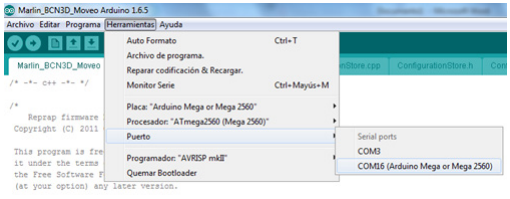
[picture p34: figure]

Para acabar hay que hacer click en botón de subir. Después de aproximadamente 1 minuto el firmware se habrá subido correctamente. Si hay problemas en la compilación descargar los drivers más actualizados desde la web de Arduino.

Finally, you must click the button “upload”. After about 1 minute firmware will be uploaded. If there are problems in the compilation, download the most current drivers from the website of Arduino.

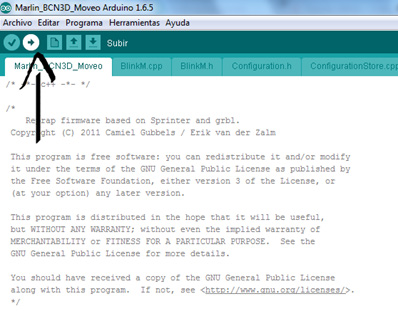
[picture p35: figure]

## ¿Cómo usar el BCN3D Moveo? How to use the BCN3D Moveo?

Pronterface

Pronterface es un programa destinado al testeo de impresoras 3D. Con él se pueden mover todos los ejes individualmente hacia todas las direcciones y también los extrusores. En la parte derecha hay un terminal de comandos con el que se pueden enviar líneas de gcode para mover los motores, leer las posiciones de cada motor y mover servo motores.
En nuestro caso, haremos uso del software Pronterface con el objetivo de mover el BCN3D Moveo. Para poder actuar sobre el BCN3D Moveo hay que establecer una comunicación entre Pronterface y el Arduino. Esto se consigue realizando los siguientes pasos. Primero se tiene que escoger el puerto COM en el que esté conectado el arduino.

Pronterface

Pronterface is a program for the testing of 3D printers. With it you can move all axes individually in all directions and also the extruders of your printer. On the right side of the program, there is a terminal command with which you can send gcode lines to move steppers, read the positions of each stepper and also move servo motors.
In our case, we will use the software Pronterface in order to move the BCN3D Moveo. To act on the BCN3D Moveo we must establish communication between Pronterface and Arduino. This is accomplished by performing the following steps.

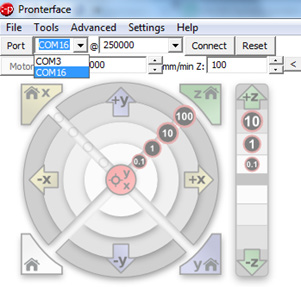
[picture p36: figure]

Atención: No se deben tener abiertos los dos programas (Pronterface y Arduino IDE) a la vez.

Please note that should not be open both programs (Pronterface and Arduino IDE) simultaneously.

## ¿Cómo usar el BCN3D Moveo? How to use the BCN3D Moveo?

El siguiente paso es escoger una velocidad de
250.000 baudios.

The next step is to choose a speed of 250,000 baud.

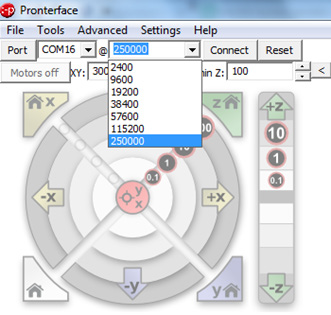
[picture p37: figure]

Finalmente para acabar de realizar la conexión hacer click en el botón “Connect”. Entre otras cosas aparecerá un texto notificando que nuestra impresora ya está online “Printer is now online”. A partir de ese momento se activará la función del terminal (situada en la parte inferior derecha) y la de mover los motores.
El círculo superior izquierdo nos muestra 3 de los 5 ejes (los principales). Con el movimiento de esos 3 ejes se pueden realizar aproximaciones y tests para encontrar las posiciones que más se adecúen a la secuencia de trabajo que se requiera. Una vez se hayan encontrado las posiciones el procedimiento es el de escribir un Gcode que contenga toda esa información.

Finally, to finish the connection, click the “Connect” button. Among other things, a text will appear notifying you that your printer is online “Printer is now online.”
From that moment, the function of the terminal (located on the bottom right) and the function of moving the motors will be activated.
The upper left circle shows 3 of the 5 axis (the main axis). With the movement of those 3 axes you can perform tests to find approaches and positions that are most suited to the sequence of work required. Once the positions have been found, the procedure is to write a .Gcode containing all this information.

## ¿Cómo usar el BCN3D Moveo? How to use the BCN3D Moveo?

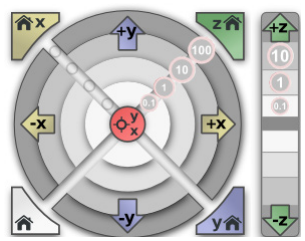
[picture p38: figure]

En éste círculo también se aprecian distintos valores, del 0.1 al 100. La unidad usada en los valores se refiere a un paso de los motores. Por norma general, cuando estamos testeando no se recomienda usar las opciones de 100 pasos.

In this circle also they appreciate different values, from 0.1 to 100. The unit used in the securities refers to a step of the engines. Generally, when we are testing, it is not recommended to use options 100 steps.

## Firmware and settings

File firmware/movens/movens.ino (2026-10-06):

/**

  Movens

  - Copyright (C) 2024 - PRESENT  rookidroid.com
  - E-mail: info@rookidroid.com
  - Website: https://rookidroid.com/

                        **
                       ****
                        **
                        **
                        **
                        **

        **********************************
      **************************************
     ****************************************
     ********      ************      ********
     *******        **********        *******
     *******        **********        *******
     ********      ************      ********
     ****************************************
     ****************************************
     ****************************************
     ****************************************


            **************************

                ******************

*/

/*
   Module layout
     movens_config.h   pins, servo range, WiFi credentials
     joints.*          stepper engine, J1-J5 steppers, hand servo
     calibration.*     steps <-> degrees, soft limits, NVS persistence
     kinematics.*      forward / inverse kinematics (tool pose <-> joint angles)
     commands.*        FreeRTOS queue bridging web callbacks (Core 0) to loop() (Core 1)
     connectivity.*    WiFi station / access point fallback, saved network, OTA
     web_server.*      async HTTP routes / REST API
     web_*.h           embedded HTML / CSS / JS
     json_util.*       minimal JSON number parsing
*/

#include "calibration.h"
#include "commands.h"
#include "joints.h"
#include "connectivity.h"
#include "web_server.h"

void setup() {
  Serial.begin(115200);

  loadCal();
  setupWiFi();
  setupOTA();
  setupJoints();
  setupCommandQueue();
  setupWebServer();
}

/* ─────────────────────────────────────────────
   loop()  — runs on Core 1
   Drains the command queue so all motor / servo
   API calls happen here, away from Core 0 lwIP.
   ───────────────────────────────────────────── */
void loop() {
  handleNetwork();

  processCommands();

  // Persist calibration once all joints are idle
  if (calDirty() && !anyStepperRunning()) saveCal();

  // Yield to FreeRTOS scheduler so the WiFi task (Core 0) and other
  // system tasks get CPU time every loop iteration.
  vTaskDelay(1);
}

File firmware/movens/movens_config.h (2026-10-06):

#pragma once

/* ─────────────────────────────────────────────
   Hardware and network configuration
   ───────────────────────────────────────────── */

/* ── Joint stepper pins ── */
#define J1_DIR  13
#define J1_STEP 12

#define J2_DIR  14
#define J2_STEP 27

#define J3_DIR  26
#define J3_STEP 25

#define J4_DIR  33
#define J4_STEP 32

#define J5_DIR  15
#define J5_STEP 2

#define NUM_STEPPERS 5  // joints are numbered 1..NUM_STEPPERS

/* ── Stepper defaults ── */
#define STEPPER_SPEED_HZ 3000  // steps/s
#define STEPPER_ACCEL    800   // steps/s²

/* ── Hand servo ── */
#define servoPin 4
const int SERVO_MID = 1500;
const int SERVO_MIN = 700;
const int SERVO_MAX = 2300;

/* ── WiFi ──
   At boot the robot joins the network saved from the web UI (Network page).
   If none is saved, or it can't connect within WIFI_CONNECT_TIMEOUT_MS, it
   starts its own access point instead (http://192.168.4.1). */
#ifndef APSSID
  #define APSSID "movens"
  #define APPSK  "movens_1234"
#endif
#define WIFI_HOSTNAME           "movens"  // also mDNS: http://movens.local
#define WIFI_CONNECT_TIMEOUT_MS 15000

/* ── Arm geometry for kinematics (mm) ──
   NOMINAL values: measure your arm and update them.
   Frame: origin on the J1 axis at the base mounting surface, +Z up,
   +X forward at J1 = 0. Joint angles (deg) must follow these conventions,
   so calibrate each joint's home / direction to match:
     J1  yaw about +Z. 0 = arm faces +X, + = counter-clockwise seen from above
     J2  shoulder.     0 = upper arm vertical, + = tilts forward (toward the reach)
     J3  elbow.        0 = forearm in line with upper arm, + = bends forward
     J4  wrist roll.   0 = J5 axis parallel to J2 axis, + = right-handed about the forearm
     J5  wrist pitch.  0 = gripper in line with forearm, + = bends forward (at J4 = 0)
   All zero = arm pointing straight up. */
#define KIN_D1 232.0f  // base -> J2 axis height
#define KIN_A1   0.0f  // forward offset of J2 axis from J1 axis
#define KIN_A2 221.0f  // J2 axis -> J3 axis
#define KIN_D4 223.0f  // J3 axis -> J5 axis, along the forearm
#define KIN_A3   0.0f  // forearm axis offset from J3 axis (+ = forward of the forearm)
#define KIN_D6 175.0f  // J5 axis -> tool point (fingertip centre)

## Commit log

2026-10-03 Modularize firmware and add calibration
    This commit splits the original monolithic Arduino sketch into focused modules for joints, calibration, commands, connectivity, and web serving. It adds persisted joint calibration data in NVS with s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
2026-10-03 Add IK cartesian control and sync moves
    This change adds a forward/inverse kinematics model for the arm and exposes Cartesian pose control via the web UI and REST endpoint. It also introduces synchronized multi-joint motion so all steppers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
2026-10-03 Redesign web UI and add config support
    This commit refreshes the Moveo web interface with a modern app-bar layout, richer control/calibration panels, and adaptive status polling. It also adds GET /config support and exposes the current joint speed and acceleration values used by CMD_CONFIG so the frontend can display and edit motion settings.
    [commands.cpp, web_app_css.h, web_server.cpp]
2026-10-06 Add WiFi network config and calibration updates
    This adds saved WiFi credentials with station/AP fallback, a new /network page, and OTA/network restart handling. It also improves calibration persistence by storing per-joint motion defaults, suppor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
2026-10-06 Add favicon/logos and integrate brand SVG
    Add browser favicon and logo assets, and integrate an inline brand SVG into the web UI. New files: logo/* SVGs and FIRMWARE/moveo_arduino/web_favicon_svg.h (PROGMEM). Serve /favicon.svg via web_serve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
2026-10-06 Rename project to Movens and update firmware
    This change rebrands the repo and firmware from Moveo to Movens, including renamed config files, WiFi/AP defaults, embedded web UI text, logo assets, and CAD file names. Calibration data remains comp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
    [movens base wheel.step, movens base.step, movens j2.step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]
2026-10-06 Rename firmware project to Movens
    This change renames the Arduino firmware project from moveo_arduino to movens and updates the corresponding source, header, and sketch file paths. The code itself remains unchanged; this is a project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
2026-10-07 Reorganize repo: lowercase layout, archive Moveo and legacy files
    - FIRMWARE/movens -> firmware/movens
    - Original BCN3D Moveo files (SolidWorks CAD, Marlin firmware, BOM,
    user manual) -> archive/moveo
    - Superseded Movens files (old movens.f3d, parts.f3d, 1M3A.STEP,
    uno box, temp STLs) -> archive/legacy
    - Add archive/README.md and update README paths and layout table
    [1M1B.SLDPRT, 1M2A.SLDPRT, 1M3.SLDASM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]
2026-10-13 Support ESP32-S3 and improve WiFi diagnostics
    This change adds ESP32-S3-safe stepper pin mappings and removes the legacy ESP32Servo dependency in favor of LEDC servo control to avoid driver conflicts. It also records the saved-network join failure reason at boot, surfaces that error in the network status page, and clarifies the 2.4 GHz WiFi requirement and fallback messaging in the UI.
2026-10-17 Update ESP32-S3 pin mapping
    Remap joint stepper pins for ESP32-S3, move the servo output to GPIO 1, and update the legacy parts design.
